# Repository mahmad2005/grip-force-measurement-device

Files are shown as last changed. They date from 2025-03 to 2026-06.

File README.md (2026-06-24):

# Hand Grip Force and Trajectory Measurement System

## Overview

This project focuses on the development of a portable, intelligent device designed to measure **hand grip force** and **object trajectory** for neurological assessment, particularly in patients with **stroke** or **Multiple Sclerosis (MS)**.

## Key Features

- 🧠 **Neurological Focus**  
  Designed to evaluate motor function, coordination, and rehabilitation progress in stroke and MS patients.

- 🔧 **Core Technologies**
  - **STM32 Microcontrollers** – Real-time data acquisition and processing
  - **Pressure Sensors** – High-resolution spatial grip force measurement
  - **Gyroscope & IMU Sensors** – Motion and orientation tracking of held objects
  - **Bluetooth** – Wireless data transmission to PC/mobile apps
  - **RTOS** – Deterministic multitasking on embedded systems
  - **Embedded Linux** – Advanced data handling and UI support

## System Architecture

[ Pressure Sensor ] [ Gyroscope / IMU ]
| |
[ Analog Front End ] |
| |
[ STM32 MCU ] <--> [ Bluetooth Module ]
|
[ Data Logger / Wi-Fi ]
|
[ Embedded Linux Platform ]

## Use Case

The system enables clinicians and researchers to:
- Quantitatively assess hand grip strength and control
- Track and visualize object movement during gripping tasks
- Analyze neuromuscular impairments and rehabilitation outcomes

## Future Work

- 🔬 Integration with AI models for predictive analysis  
- 📱 Mobile app for real-time data visualization  
- 🌐 Cloud-based data synchronization and reporting

---

**Developed using:**  
`C/C++ (STM32 HAL)`, `FreeRTOS`, `Python`, `Embedded Linux`, `Bluetooth Low Energy (BLE)`

---

> 📍 *This project is part of ongoing research in neuromuscular assessment and assistive rehabilitation technology.*

## � Developer Docs and Quick Start

- Protocol and wiring details (pins, SPI/UDP framing): `docs/System_Protocol_and_Wiring.md`
- Hardware overview and BOM highlights: `hardware/README.md`

Visualizer quick start (Windows cmd):

1) Install Python packages
  - Open a terminal and run:
    - `python -m pip install -r software\requirements.txt`
2) Set your listen IP/port in `software\viz_config.json` if needed (defaults to 0.0.0.0:12345)
3) Run the visualizer
  - `python software\run_visualizer.py`

Make sure the ESP32 sketch `firmware/esp32/ESP32_C3_Zero_SPI_2048_UDP.ino` has `udpAddress` set to your PC’s IP.

## �🔧 New Design

This section features the redesigned pressure sensor and control PCB with updated layout and schematic.

| Front View | Back View |
|---|---|
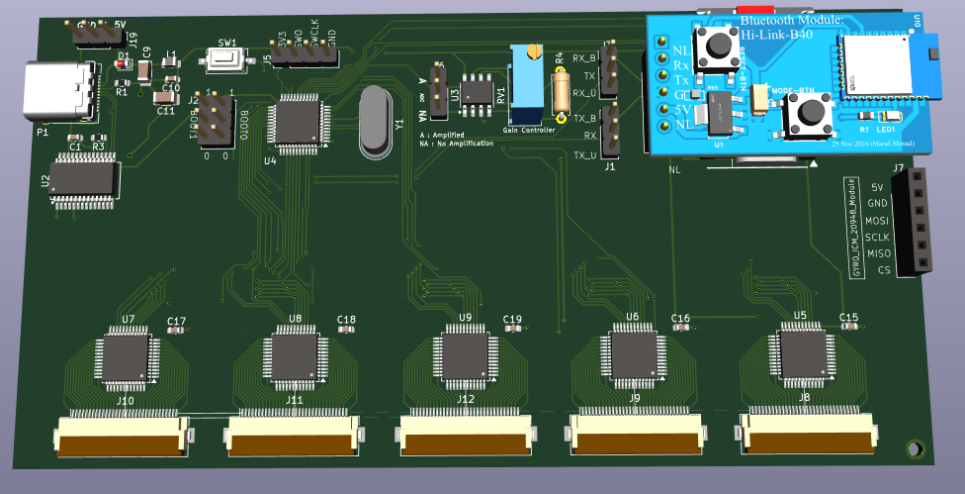
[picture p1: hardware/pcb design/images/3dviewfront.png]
3D View Front
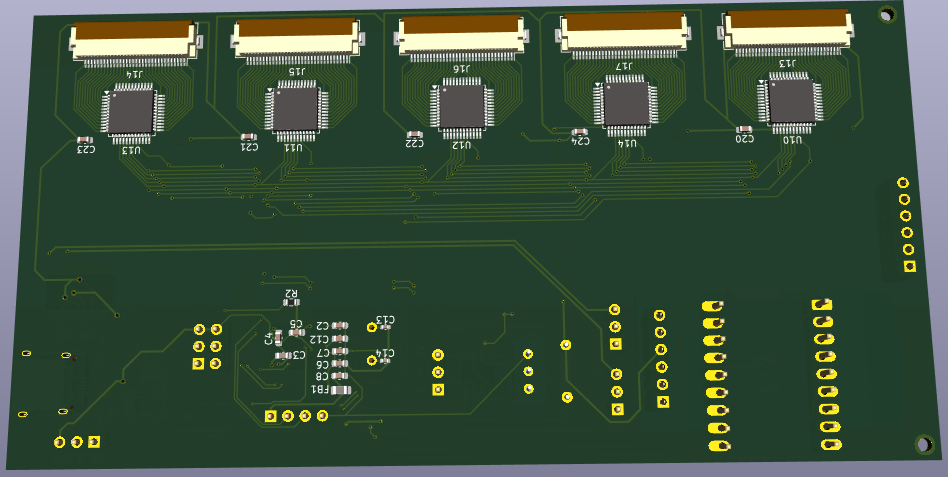
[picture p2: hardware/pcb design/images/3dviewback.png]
3D View Back
|  |  |
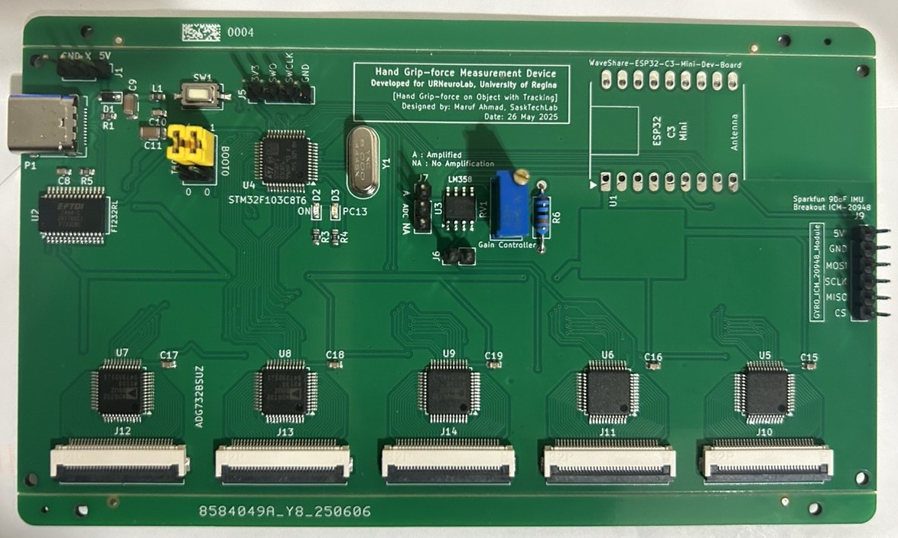
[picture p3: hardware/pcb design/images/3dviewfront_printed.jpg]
3D View Front
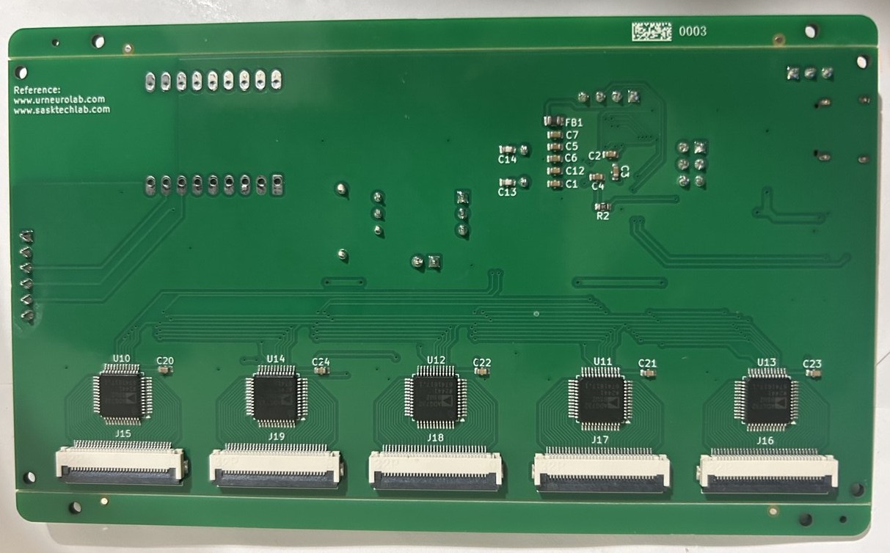
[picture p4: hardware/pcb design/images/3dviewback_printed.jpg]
3D View Back
|  |  |

### 🧩 Schematic

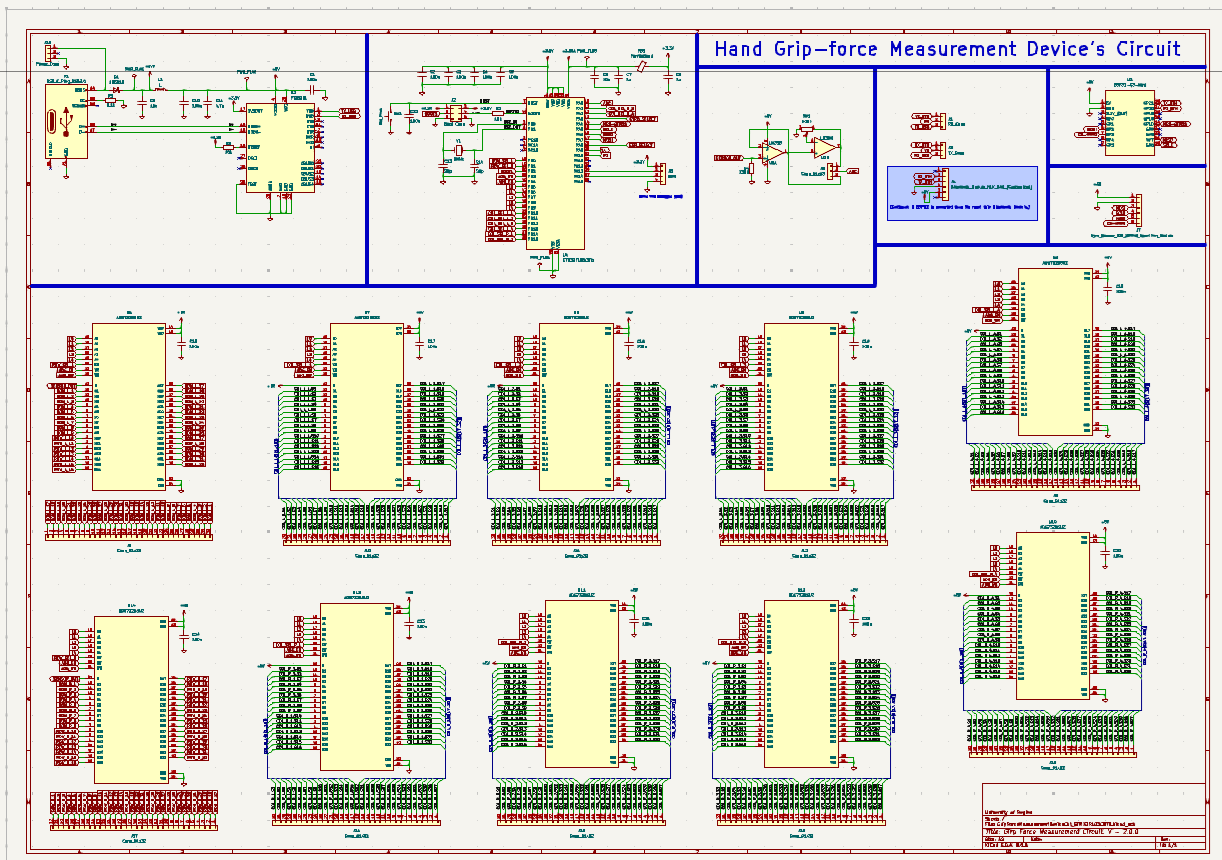
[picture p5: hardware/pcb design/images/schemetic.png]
Schematic


### 3D View of the Pressure Sensor Pad
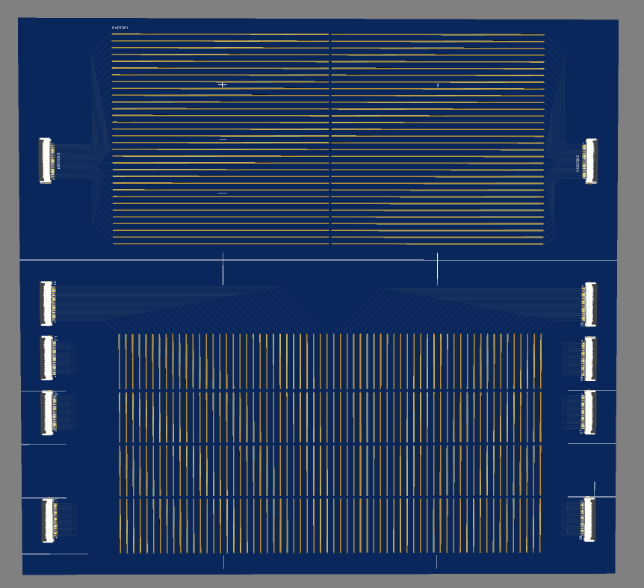
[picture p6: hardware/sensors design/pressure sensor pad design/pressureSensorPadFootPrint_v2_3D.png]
Pressure Sensor Pad 3D


## 📂 Previous Design

This section showcases the earlier versions of the PCB and sensor module designs for the Hand Grip Force Measurement Device.

| 3D View | 3D View (with Bluetooth Module) |
|---|---|
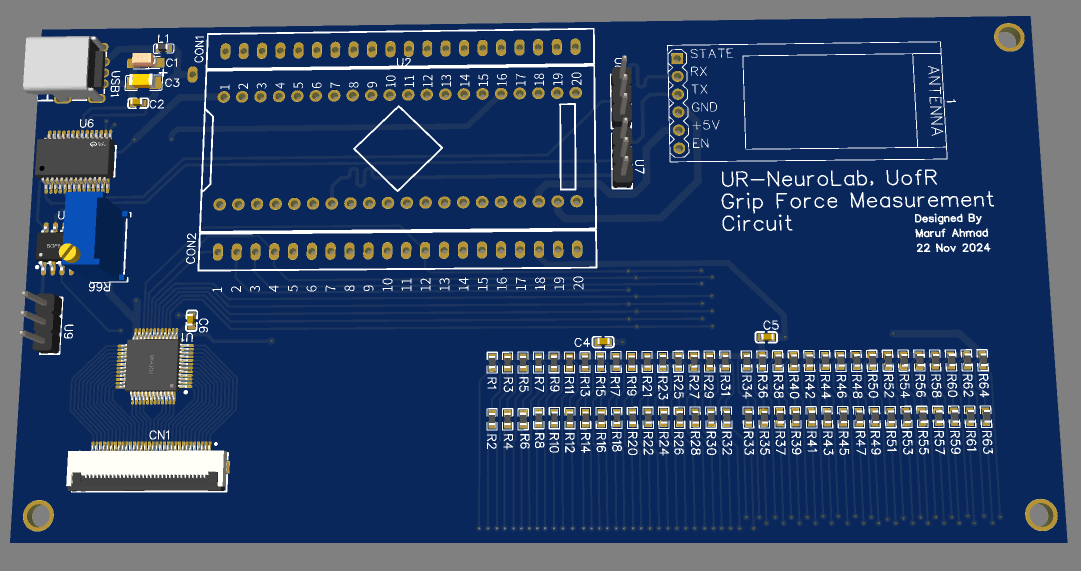
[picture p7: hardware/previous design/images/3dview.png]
3D View
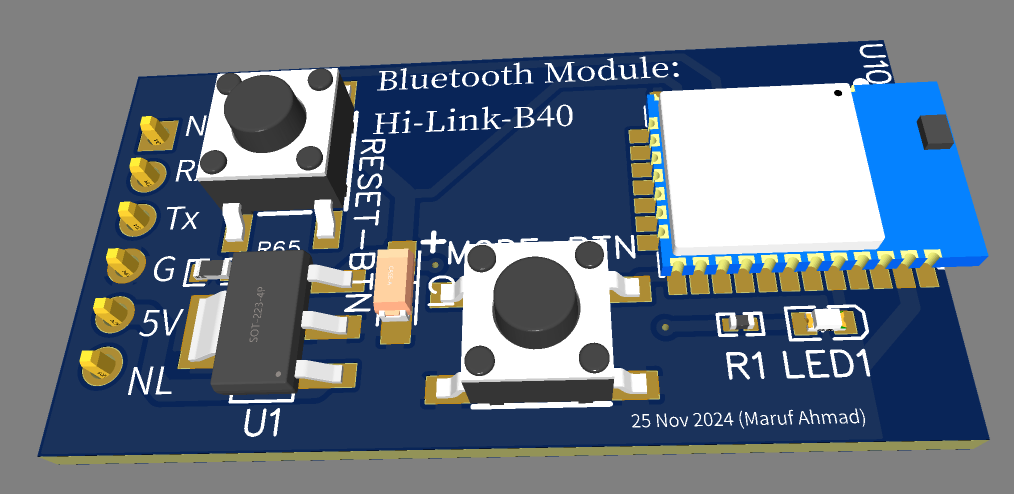
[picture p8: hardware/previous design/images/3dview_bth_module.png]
3D View BTH Module
|  |  |

| PCB Layout | PCB Layout (with Bluetooth Module) |
|---|---|
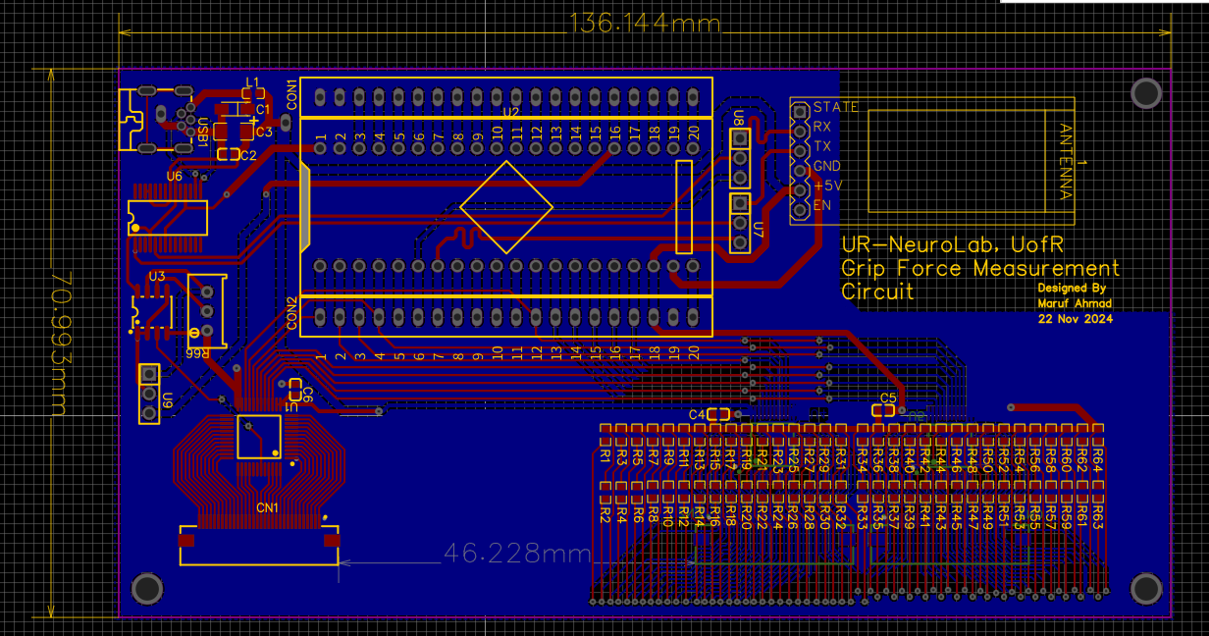
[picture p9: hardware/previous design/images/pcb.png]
PCB
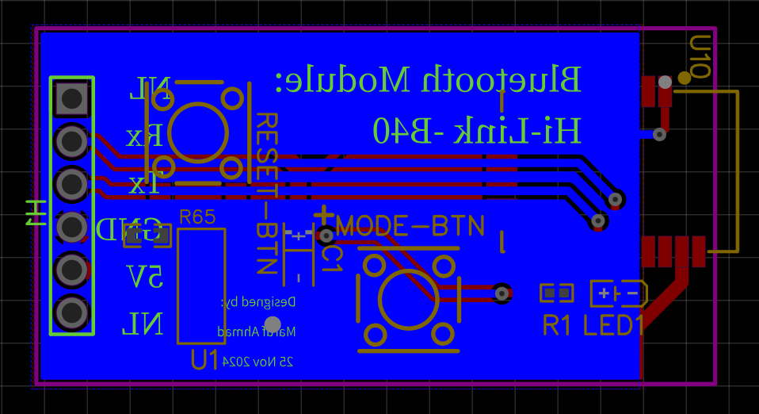
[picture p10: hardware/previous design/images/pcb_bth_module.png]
PCB BTH Module
|  |  |

### 🧪 Assembly and Testing Photos

These images capture key stages of the prototype development, including hardware assembly, sensor components, and testing setup.

| Internal Circuit | Grip Force Testing | PCB in Action |
|---|---|---|
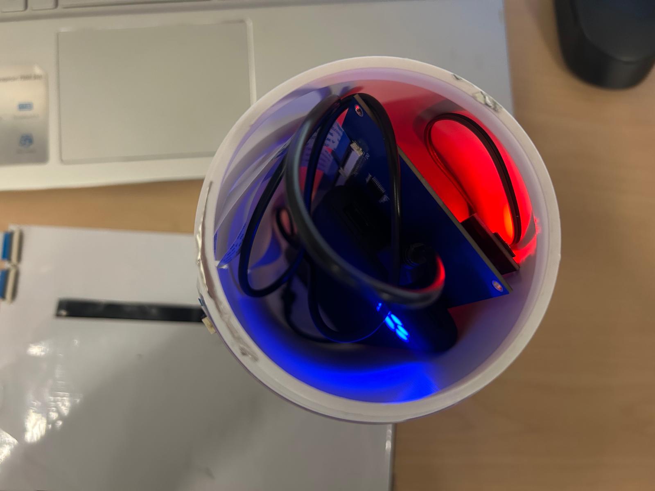
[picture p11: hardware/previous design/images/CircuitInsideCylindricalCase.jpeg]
Circuit Inside
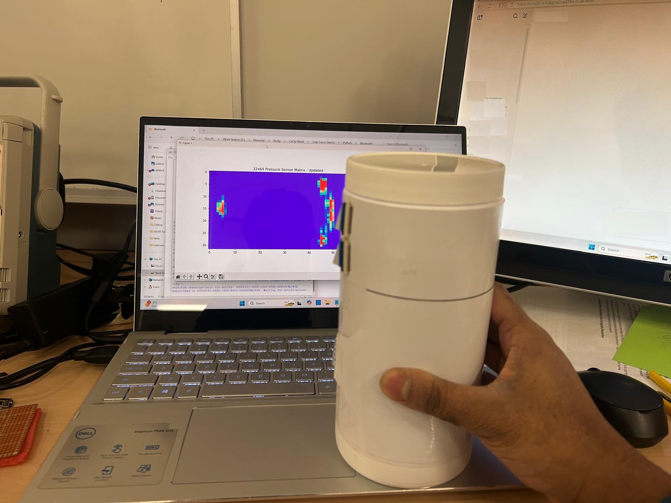
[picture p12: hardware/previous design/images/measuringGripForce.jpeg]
Grip Force Test
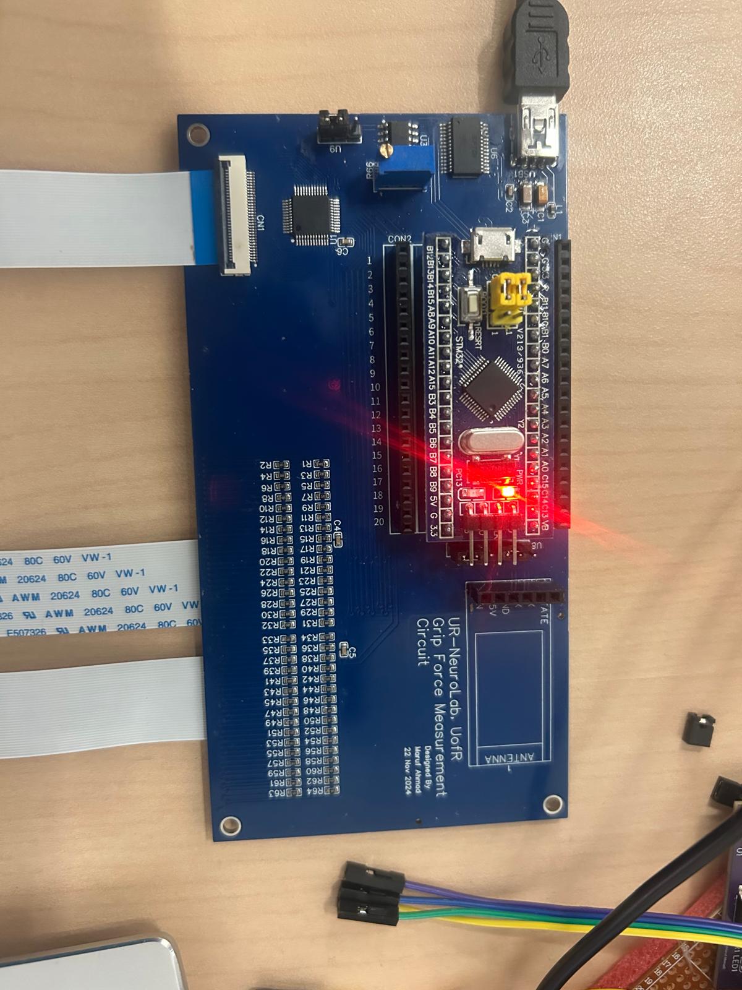
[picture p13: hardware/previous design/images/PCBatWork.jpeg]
PCB at Work
|  |  |  |

These photos show physical testing and assembly steps:
- Internal circuit mounted inside a cylindrical 3D-printed case.
- Testing hand grip force with the pressure sensor system connected to a display.
- Powered PCB with Bluetooth module running in real hardware.

| Pressure Sensor Pad | Pressure Sensing Demo |
|---|---|
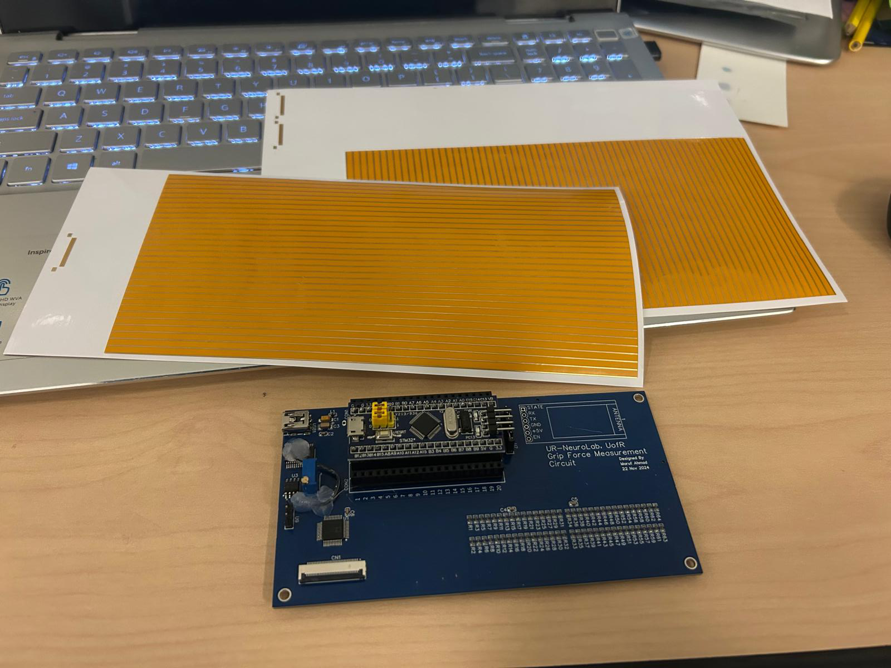
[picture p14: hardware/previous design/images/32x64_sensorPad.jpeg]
Sensor Pad
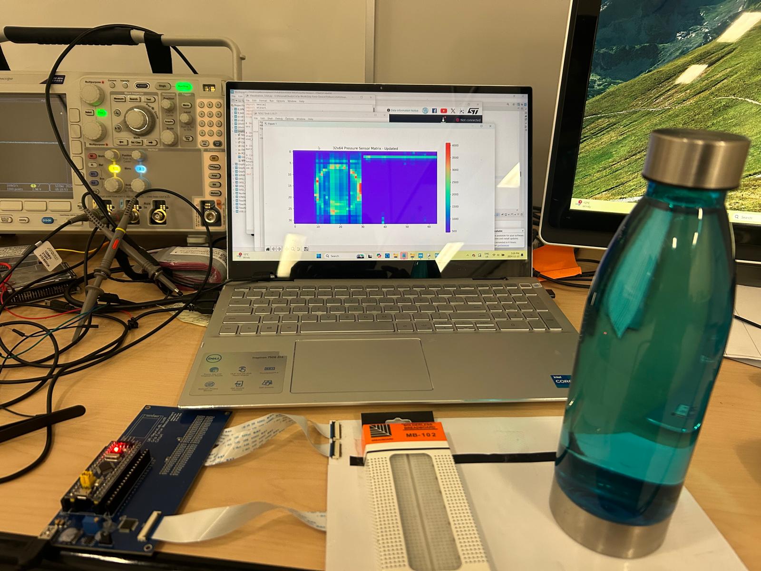
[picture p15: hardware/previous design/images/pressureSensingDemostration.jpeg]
Demo Setup
|  |  |

## Application View

Below is a sample visualization of the grip force device showing the **32×64 pressure map** along with gyroscope, accelerometer, and magnetometer data:

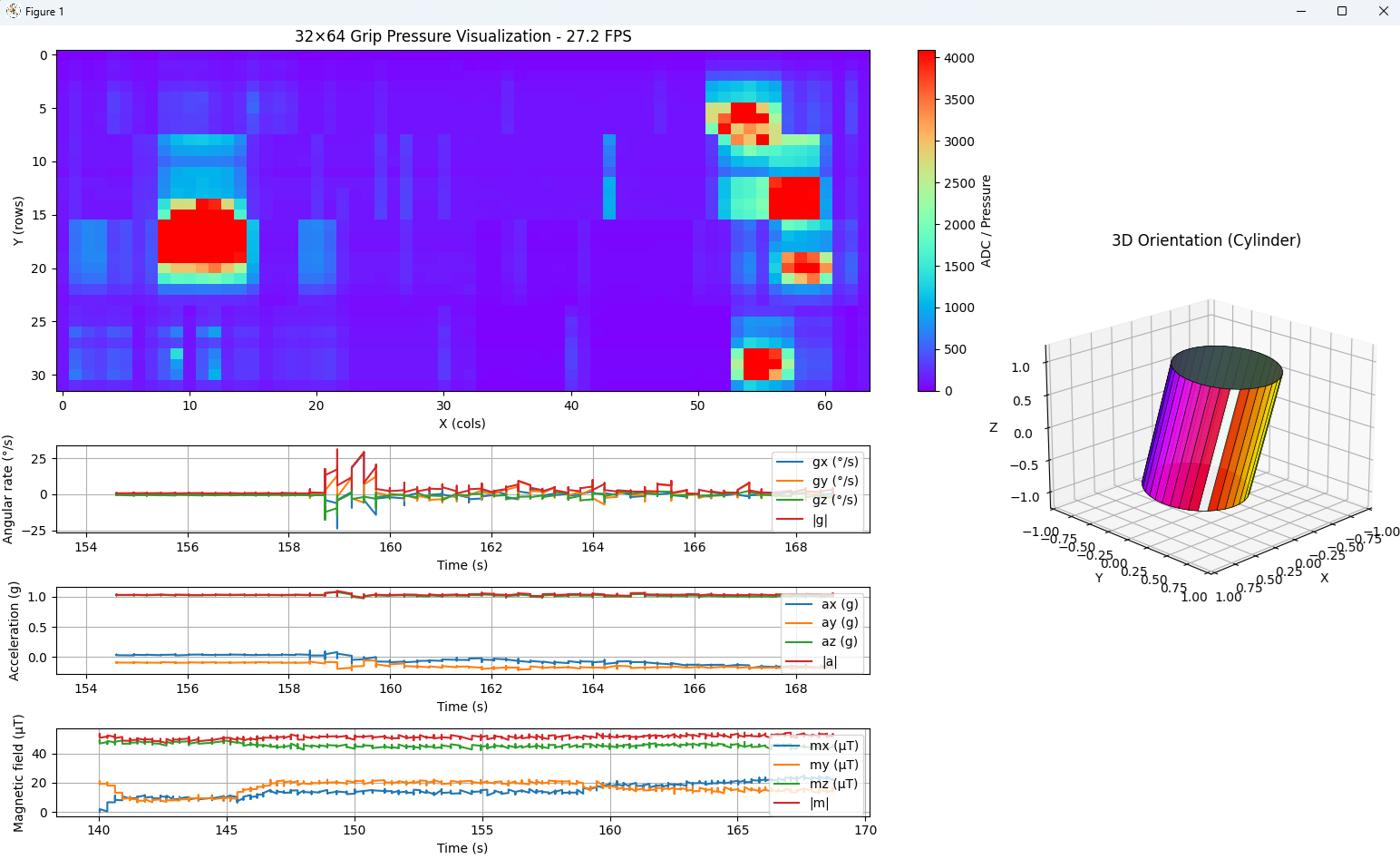
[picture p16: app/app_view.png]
Application View


## 🎥 Demonstration Video

Real-Time AprilTag Cylinder Tracking (https://www.youtube.com/watch?v=EXzzfofSnuo)

**Real-Time AprilTag Cylinder Tracking with 2D/3D Overlap Visualization**

Click the image above to watch the demonstration video on YouTube.

## 📄 Video Description

This video demonstrates a **real-time vision-based tracking system** using **AprilTags** to estimate and visualize the position of a cylindrical object.  
The system overlays **2D and 3D representations** to show precise alignment and movement tracking, supporting validation of object trajectory and spatial accuracy for experimental and rehabilitation-focused applications.

---

## 🎬 Recent Updates & New Demonstration

### New GripForce 3D Viewer Demo

GripForce 3D Viewer Software Outlook (https://www.youtube.com/watch?v=9zOydEpcdT4)

**Watch the new 3D Viewer software demonstration:**  
[GripForce 3D Viewer Software Outlook – YouTube](https://www.youtube.com/watch?v=9zOydEpcdT4)

This video showcases the updated **3D visualization interface** with improved **pressure heatmap display**, **real-time IMU data plots**, and **orientation cylinder rendering**.

### Updated 3D Simulator Visual

A new high-resolution screenshot showing the **GripForce 3D Simulator interface** is now available:

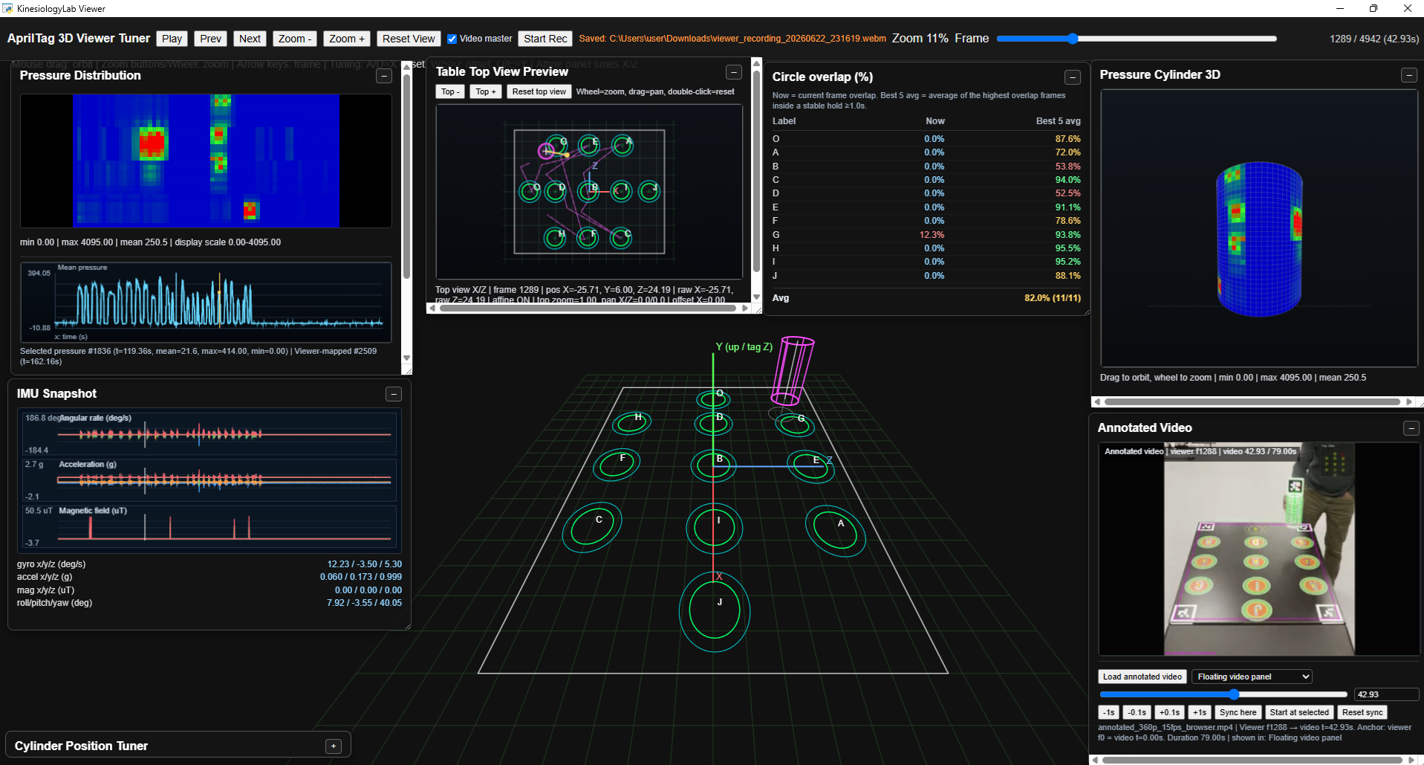
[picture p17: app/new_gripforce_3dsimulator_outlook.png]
GripForce 3D Simulator Outlook


**Recent updates:** Improve viewer sync, graph zoom, and persistent panel layout

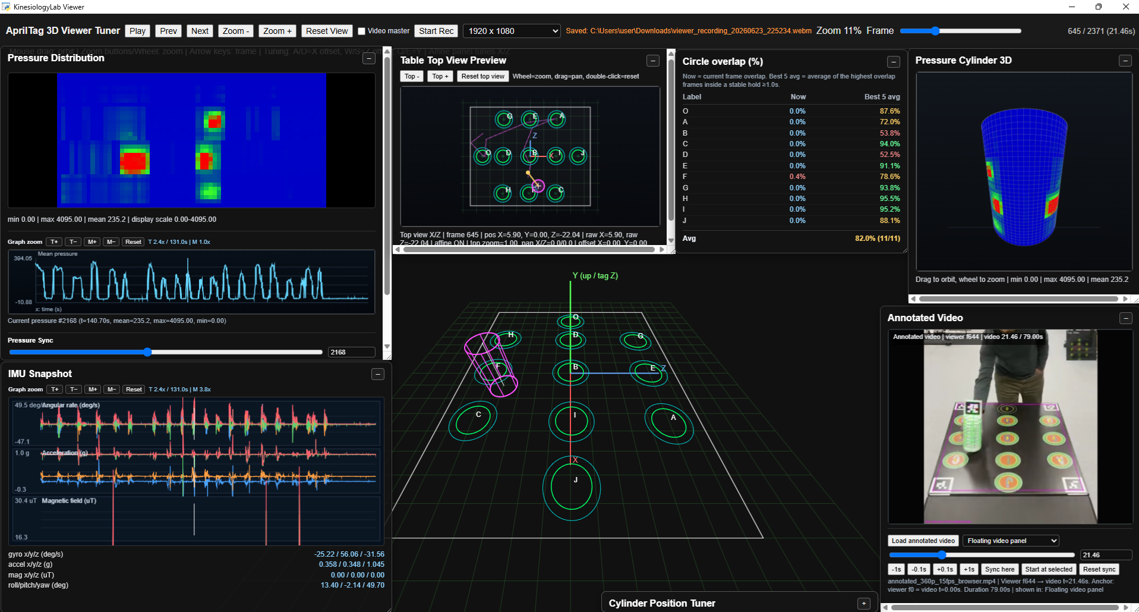
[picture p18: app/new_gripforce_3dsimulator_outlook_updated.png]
GripForce 3D Simulator Outlook


This demonstrates the enhanced UI with:
- Realistic 3D pressure blob movement
- Real-time gyroscope, accelerometer, and magnetometer traces
- 3D orientation object (cylinder) rendering
- Adjustable FPS and parameter controls

---

## 🖥️ Application Components

### Pressure Distribution Visualization

- **32×64 heatmap** showing live grip force across the entire sensor pad
- **Adaptive color scaling** with configurable min/max pressure (default: 0–4095)
- **Transformation options**: flip, rotate, or half-mirror for sensor orientation
- **Real-time animation** at ~60 fps (configurable)
- **Non-stretching display**: maintains aspect ratio during window resize

### IMU Data Visualization

- **3 simultaneous data streams**:
  - **Gyroscope**: angular velocity (°/s) at ±250 dps
  - **Accelerometer**: linear acceleration (g) at ±2 g
  - **Magnetometer**: magnetic field (µT)
- **Dual plot modes**:
  - **Per-component**: separate traces for X, Y, Z channels
  - **Magnitude-only**: single trace per sensor type
- **Sliding window buffer**: default 800 samples, configurable
- **Real-time animated plots** with live data injection

### 3D Object Orientation

- **Interactive 3D cylinder** representing held object
- **Quaternion-to-rotation-matrix** conversion from IMU orientation
- **Real-time 3D rendering** alongside 2D plots
- **Optional mode**: can be toggled on/off in visualizer

### Simulator (No Hardware Needed)

- **Realistic pressure patterns**: moving circular blobs with velocity
- **Simulated IMU oscillations**: smooth gyro, accel, mag data
- **UDP broadcast**: sends packets identical to real hardware
- **Interactive mode**: optional GUI for parameter control (`simulator_gui.py`)
- **Perfect for testing** without connected hardware

---

## 🌐 Web Viewer & Pose Acquisition

### Standalone Desktop Viewer

A **pywebview-based desktop application** for viewing 4K video annotated with AprilTag pose data:

```bash
# Launch from command line:
python run_viewer_standalone.bat

# Or manually:
python app/device_pose_acquisition/auto_target_detections/viewer_7371/standalone_viewer.py
```

**Features**:
- Frame-by-frame playback of annotated video
- Overlay circles and pose estimation data
- Synchronized pressure and IMU timeline (if available)
- Portable: single HTML file with embedded data

### AprilTag Pose Detection & Video Annotation

Process 4K video to detect **cylinder position and orientation** using AprilTags:

```bash
python app/device_pose_acquisition/auto_target_detections/detect_apriltag_pose_fixed11_4k.py \
  --video input.mp4 \
  --annotated-out output.mp4 \
  --export-viewer-data viewer_folder \
  --process-fps 15
```

**Output**:
- **Annotated MP4**: overlays detected circles and pose estimates
- **Viewer Data JSON**: frame-by-frame detection results
- **Viewer HTML**: self-contained, portable viewer with embedded data

**Optional Processing**:
- `--start-frame N, --end-frame N`: process specific frame range
- `--undistort`: apply camera calibration correction
- `--max-frames 0`: process all frames (default)

### Video Resizing for Web Playback

Optimize annotated videos for browser streaming:

```bash
# 720p
ffmpeg -vf "scale=1280:-2" -c:v libx264 -crf 23 input.mp4 output_720p.mp4

# 360p, 15 fps
ffmpeg -vf "fps=15,scale=-2:360" -c:v libx264 -crf 27 input.mp4 output_360p_15fps.mp4

# 240p, 15 fps
ffmpeg -vf "fps=15,scale=-2:240" -c:v libx264 -crf 28 input.mp4 output_240p_15fps.mp4
```

---

## 📁 App Folder Contents & File Guide

### `app/` Directory Structure

```
app/
├── app_view.png                           # Screenshot of pressure + IMU visualizer
├── new_gripforce_3dsimulator_outlook.png  # New 3D simulator interface screenshot
├── 3dsimulator_view.png                   # 3D simulator demo view
├── README.md                              # App-specific documentation
│
├── device_data_acquisitiom/               # Real-time data acquisition & visualization
│   ├── simulator.py                       # Simulates realistic pressure/IMU data (no hardware)
│   ├── simulator_gui.py                   # Interactive GUI for simulator
│   ├── viz_full_with_gyro_accel_mag.py    # Standard 2D visualizer
│   ├── viz_full_with_gyro_accel_mag_3Dobj.py  # 2D visualizer + 3D cylinder
│   ├── run_viz_app.bat                    # Launcher for standard visualizer
│   ├── run_viz_3D.bat                     # Launcher for 3D visualizer
│   └── README.txt                         # Device acquisition documentation
│
└── device_pose_acquisition/               # Video processing & web viewer
    ├── 4k_video_process/
    │   ├── extract_frames.py              # Extract frames from video
    │   ├── manual_reference_circle_alphabet_labeler_4k_best_images.py  # Reference marker UI
    │   ├── sessions/                      # NDJSON pressure/IMU replay data
    │   │   ├── session1.ndjson
    │   │   ├── session_2.ndjson
    │   │   └── ...
    │   └── accuracy_analyzer/
    │       ├── Note.txt                   # Command examples for video processing
    │       └── detect_apriltag_pose_*.py  # Various AprilTag detection scripts
    │
    └── auto_target_detections/
        ├── detect_apriltag_pose_fixed11_4k.py  # Main AprilTag detector (exports viewer data)
        ├── extract_frames.py              # Frame extraction utility
        └── viewer_7371/                   # Web viewer assets
            ├── viewer.html                # Portable viewer template
            ├── viewer_data.json           # Exported frame data
            ├── standalone_viewer.py       # Desktop launcher
            └── session.ndjson, session_2.ndjson  # Example session files
```

### How to Use Each File

| File | Usage |
|---|---|
| **simulator.py** | Start with `python simulator.py --ip 127.0.0.1 --port 12345 --fps 60` to test visualizer without hardware |
| **viz_full_with_gyro_accel_mag.py** | Main visualizer; shows pressure + IMU data |
| **viz_full_with_gyro_accel_mag_3Dobj.py** | Enhanced visualizer with 3D object rendering |
| **detect_apriltag_pose_fixed11_4k.py** | Process 4K video to export annotated frames and viewer data |
| **viewer.html** | Open in browser or desktop app to view posed video frames |
| **session*.ndjson** | Replay recorded pressure/IMU data; import into analysis tools |

---

## 📊 Data Formats

### Pressure Data

- **32 rows × 64 columns** (2048 total samples per frame)
- **UDP packets**: 10 packets per frame, 205 uint16 values per packet
- **Data type**: uint16, little-endian
- **Range**: 0–4095 (raw 12-bit ADC)
- **Default endpoint**: UDP `0.0.0.0:12345`
- See `docs/System_Protocol_and_Wiring.md` for detailed packet structure

### IMU Data

- **Gyroscope**: ±250 dps (131.0 LSB/deg/s)
- **Accelerometer**: ±2 g (16384.0 LSB/g)
- **Magnetometer**: ±120 µT (0.15 µT/LSB, AK09916 sensor)
- **Update rate**: ~60 fps (synchronized with pressure frames)
- **Format**: big-endian int16 values with header: `b'\xAA\x55IM'`

### Viewer Data (JSON Export)

- **Self-contained HTML** with embedded frame data
- **Per-frame annotations**: circle overlays, pose estimates, detection results
- **Portable format**: open in any browser or desktop viewer
- Generated by `detect_apriltag_pose_fixed11_4k.py --export-viewer-data <path>`

### Session Data (NDJSON)

- **Streaming-safe newline-delimited JSON**
- **One JSON object per line** (metadata + frames)
- **Contains**: frame_idx, timestamp, flattened pressure array, IMU components
- **Schema**: `kinesiology.pressure_imu.ndjson.v1`
- **Use case**: replay in web viewer, time-series analysis

---

## 🎯 Quick Start Guide

### 1. **Test Without Hardware** (Simulator)

```bash
# Terminal 1: Run simulator
cd app/device_data_acquisitiom
python simulator.py --ip 127.0.0.1 --port 12345 --fps 60

# Terminal 2: Run visualizer
python viz_full_with_gyro_accel_mag.py --ip 0.0.0.0 --port 12345 --show-magnitude
```

Or use batch files:
```bash
run_viz_app.bat      # Standard visualizer
run_viz_3D.bat       # 3D visualizer
```

### 2. **Process 4K Video & Export Viewer Data**

```bash
cd app/device_pose_acquisition/auto_target_detections
python detect_apriltag_pose_fixed11_4k.py \
  --video path/to/video.mp4 \
  --annotated-out output.mp4 \
  --export-viewer-data viewer_output
```

Then open `viewer_output/viewer.html` in a browser or desktop viewer.

### 3. **With Real Hardware**

1. Program **ESP32** with `firmware/esp32/ESP32_C3_Zero_SPI_2048_UDP.ino` (set your PC IP)
2. Program **STM32F103C8T6** with firmware in `firmware/stm32f103c8t6/`
3. Connect pressure sensor pad to multiplexer chain (see pinouts in `docs/System_Protocol_and_Wiring.md`)
4. Run visualizer:
   ```bash
   python viz_full_with_gyro_accel_mag.py --ip 0.0.0.0 --port 12345 --show-magnitude
   ```

---

## 📖 Full Project Documentation

For comprehensive technical details, see:

- **[INSTRUCTIONS.md](INSTRUCTIONS.md)** — Project rules, data formats, development guidelines
- **[docs/System_Protocol_and_Wiring.md](docs/System_Protocol_and_Wiring.md)** — Pinouts, SPI/UDP packet structure, timing specs
- **[hardware/README.md](hardware/README.md)** — KiCad project, BOM, component references
- **[app/README.md](app/README.md)** — Visualizer usage, simulator commands, viewer workflow

---

## ❓ Frequently Asked Questions

**Q: Can I use the system without hardware?**  
A: Yes! Run the simulator (`simulator.py`) to generate realistic pressure and IMU data.

**Q: What video formats are supported?**  
A: MP4, MOV, AVI (via OpenCV). 4K video (3840×2160) is recommended for AprilTag detection.

**Q: How do I export data for statistical analysis?**  
A: Use NDJSON session files (see Session Data format) or export viewer JSON. Both are Python/R compatible.

**Q: Can I visualize multiple sessions simultaneously?**  
A: Not in the current version. Planned for future releases.

**Q: Is there a mobile app?**  
A: Mobile support is planned for future versions. Currently PC-only (Windows/Linux/Mac).

---

## 📝 Notes from Previous Work

*Summarized from `app/device_pose_acquisition/4k_video_process/accuracy_analyzer/Note.txt`:*

### AprilTag Processing: Script Variants & Frame Range Control

The project includes **three AprilTag detection script variants**. Choose based on your needs:

#### Script Variants

| Script | Use Case | Key Features |
|---|---|---|
| **detect_apriltag_pose_fixed11_4k.py** | Main production script | Full video processing, camera matrix auto-scaling |
| **detect_apriltag_pose_fixed11_4k_option3_single_state.py** | Simplified variant | Fewer options, single tracking mode |
| **detect_apriltag_pose_fixed11_4k_option3_single_state_start_end_frame.py** | **Best for testing/partial processing** | Frame range control (`--start-frame`, `--end-frame`) |

#### Key Parameters Explained

- **`--start-frame N`** — Begin processing at frame N (1-based). Default: 1
- **`--end-frame N`** — Stop processing at frame N, inclusive. Default: 0 (process until video ends)
- **`--process-fps F`** — Limit processing to F fps (e.g., 15). Skips frames to reduce computation. Default: 0 (no limit)
- **`--max-frames N`** — Process only N frames starting from `--start-frame`. Default: 0 (no limit)
- **`--annotated-out FILE`** — Write video with overlays drawn (AprilTag pose, cylinder, axes)
- **`--export-viewer-data PATH`** — Generate interactive 3D viewer HTML + JSON data to PATH folder or .json file

#### Usage Examples

**Example 1: Quick test (first 150 frames, 5 fps)**
```powershell
python detect_apriltag_pose_fixed11_4k.py `
  --video input.mov `
  --annotated-out output.mp4 `
  --max-frames 150 `
  --process-fps 5
```

**Example 2: Full video with viewer export**
```powershell
python detect_apriltag_pose_fixed11_4k.py `
  --video input.mov `
  --annotated-out output.mp4 `
  --export-viewer-data ./viewer_output `
  --process-fps 15
```

**Example 3: Frame range (test specific section, e.g., 19 June capture)**
```powershell
python detect_apriltag_pose_fixed11_4k_option3_single_state_start_end_frame.py `
  --video IMG_006_19June.mov `
  --annotated-out annotated_IMG_006_19June.mp4 `
  --export-viewer-data ./viewer_006_19June `
  --process-fps 15 `
  --start-frame 300 `
  --end-frame 900
```

#### Output Files Created

Each command generates:

- **`annotated_*.mp4`** — Video file with AprilTag overlays (boxes, axes, cylinder object)
- **`viewer_output/`** (if using `--export-viewer-data`):
  - `viewer.html` — Self-contained interactive 3D viewer (open in browser)
  - `viewer_data.json` — Extracted frame data (frame index, detected tags, poses, circle overlaps)
  - Optional: `viewer_data_overlay.json`, pose history CSV

#### Processing Tips

- **For testing**: Use `--start-frame` and `--end-frame` to process only the section you care about
- **For speed**: Reduce `--process-fps` (e.g., 5 fps processes 5 frames per second of video)
- **For accuracy**: Keep `--process-fps` high (15+) or omit it for full precision
- **For web playback**: Use FFmpeg to resize annotated videos (see next section)

### Video Format Optimization

The Note.txt includes FFmpeg commands for resizing annotated videos for web playback (720p, 360p, 240p variants).

---

## ❓ Needs Confirmation

The following items need clarification or user confirmation:

1. **New Demonstration Video Purpose**
   - URL: `https://www.youtube.com/watch?v=0S4J9DHq-p0`
   - Context: Is this a 3D viewer demo, new features showcase, or user workflow guide?

2. **Web Viewer Path Consistency**
   - Previous docs reference `web_viz_app/` but current code uses `device_pose_acquisition/auto_target_detections/viewer_7371/`
   - Should legacy paths be updated or maintained for backward compatibility?

3. **Session Data Archiving**
   - How should users manage large NDJSON files (>1 GB)?
   - Is cloud storage integration planned?

4. **Pressure Calibration**
   - Are there reference calibration procedures or known sensor limitations?
   - Should calibration UI be prioritized for next release?

5. **Multi-platform Support**
   - Current `.bat` files are Windows-only. Are Linux/macOS batch files needed?
   - Should the project add `.sh` shell scripts?

---

## Contributing & Support

For bug reports, feature requests, or contributions, please refer to the **[INSTRUCTIONS.md](INSTRUCTIONS.md)** for project rules and development guidelines.

---

> **Last Updated**: June 22, 2026  
> **Maintained by**: KinesiologyLab Team  
> **License**: [Specify as needed]

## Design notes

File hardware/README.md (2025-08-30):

# Hardware overview

This folder contains the KiCad project, 3D models, and prior design assets for the Grip Force Measurement Device.

## KiCad project

Project: `pcb design/GripForceMeasurementDeviceCkt_STM32F103C8T6/`

Key files:
- `GripForceMeasurementDeviceCkt_STM32F103C8T6.kicad_sch` — schematic
- `GripForceMeasurementDeviceCkt_STM32F103C8T6.kicad_pcb` — board layout
- `GripForceMeasurementDeviceCkt_STM32F103C8T6.pdf` — exported drawing/PDF (present)
- `gerberAll/` — manufacturing outputs

3D models and references: see `pcb design/3D-Models-Step-files/`

## BOM highlights (from IPC-2581 XML)

- MCU: STM32F103C8Tx (LQFP‑48)
- Multiplexers: ADG732BSUZ (16‑to‑1 analog switch, multiple devices used to reach 32×64)
- Wireless module: ESP32‑C3‑Mini (through‑hole variant footprint)
- IMU header: SparkFun ICM‑20948 module (6‑pin socket)

For a full BOM, open the KiCad project or review the IPC‑2581 XML at:
`pcb design/GripForceMeasurementDeviceCkt_STM32F103C8T6/GripForceMeasurementDeviceCkt_STM32F103C8T6.xml`

## Notes

- Signal levels are 3V3.
- SPI runs between ESP32‑C3 (master) and STM32F103 (slave). Ensure a clean ground reference and short interconnects.
- The sensor matrix connects to the ADG732 network; ADC measures on PA0.

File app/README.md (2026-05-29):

# KinesiologyLab Grip Pressure + IMU Visualization System

## Project Description

This project provides a real-time visualization system for a 32×64 grip pressure sensor array combined with IMU (gyroscope, accelerometer, magnetometer) data. It is designed for research or clinical applications in kinesiology, biomechanics, or hand function studies. The system can visualize live data from real hardware or from a built-in simulator that generates realistic sensor data.

### Features
- Real-time heatmap visualization of grip pressure (32×64 grid)
- Real-time plots of gyroscope, accelerometer, and magnetometer data
- 3D orientation visualization (with the 3D visualizer)
- Optional CSV logging
- Simulator for development/testing without hardware

### Screenshots

3D simulator view:

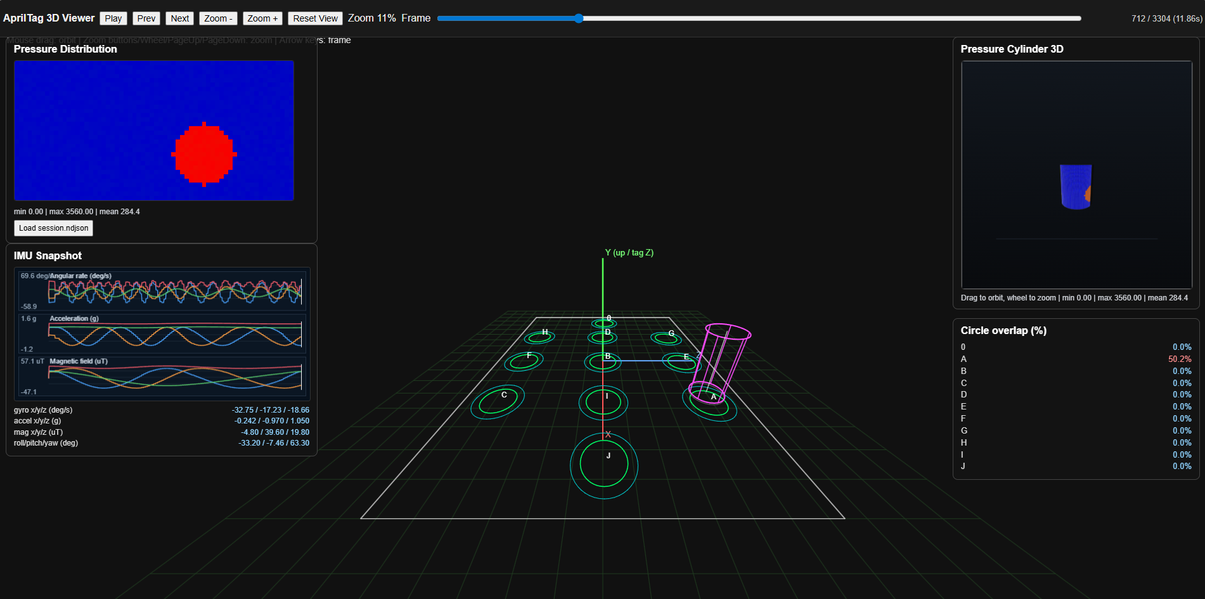
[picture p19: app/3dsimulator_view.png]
3D simulator view


App view:

App view

---

## How to Use

### 1. Run the Simulator (No Hardware Needed)
Open a terminal in the `app` folder and run:

```
python simulator.py --ip 127.0.0.1 --port 12345 --fps 60
```
- `--ip` and `--port` must match the visualizer settings (default is 127.0.0.1:12345)
- `--fps` sets the update rate (frames per second)

### 2. Run the Visualization Software
Open a second terminal in the same folder. You can use either the batch files or run the Python scripts directly.

#### Standard Visualizer
```
python viz_full_with_gyro_accel_mag.py --ip 0.0.0.0 --port 12345 --show-magnitude
```
Or simply double-click/run:
```
run_viz_app.bat
```

#### 3D Visualizer
```
python viz_full_with_gyro_accel_mag_3Dobj.py --ip 0.0.0.0 --port 12345 --show-magnitude --show-3d
```
Or simply double-click/run:
```
run_viz_3D.bat
```

### 3. See Live Simulated Data
The visualizer will display animated, realistic grip and IMU data as if real hardware is connected.

### 4. Run the Web Viewer as a Standalone Desktop App
You can open `web_viz_app/viewer_7371/viewer.html` in its own desktop window (no browser tab):

```
run_viewer_standalone.bat
```

Or run directly:

```
python web_viz_app/viewer_7371/standalone_viewer.py
```

If needed, install the dependency once:

```
python -m pip install pywebview
```

### 5. AprilTag Export Viewer Workflow (Updated)
`web_viz_app/detect_apriltag_pose_fixed11_4k.py` supports exporting viewer artifacts with:

```
python web_viz_app/detect_apriltag_pose_fixed11_4k.py --export-viewer-data web_viz_app/viewer_7371
```

Export behavior:
- Writes `viewer_data.json` (sanitized numeric export data)
- Writes `viewer.html` (portable viewer with embedded data)
- Reuses the maintained viewer template from `web_viz_app/viewer_7371/viewer.html` (fallback: `viewer2.html`) and injects fresh exported data into it

Why `viewer.html` is still written:
- Keeps a single self-contained artifact that can be opened directly (including standalone desktop mode)
- Preserves compatibility with existing workflows while still reusing the shared template code

Note:
- The current exporter intentionally updates both files for portability and backward compatibility.

---

## GUI Simulator (Recommended)

`simulator_gui.py` is a full professional virtual hardware testing tool with a dark-themed control panel.

```
python simulator_gui.py --ip 127.0.0.1 --port 12345
```

Or start streaming automatically on launch:
```
python simulator_gui.py --ip 127.0.0.1 --port 12345 --auto-start
```

### GUI Features
- Live sliders for gx/gy/gz, ax/ay/az, mx/my/mz, pressure position/radius/strength, FPS
- AUTO / MANUAL toggle buttons for IMU and pressure
- Reset IMU button
- Start/Pause streaming button
- Live pressure map preview
- IMU readings display and actual FPS counter
- **Motion Presets**: Gripping, Rolling, Shaking, Twisting, Static Hold, Random Motion
- **Record** simulated sessions to CSV
- **Replay** recorded sessions
- Dark theme

---

## Keyboard-Only Simulator (Legacy)

```
python simulator.py --ip 127.0.0.1 --port 12345 --fps 60 --manual-imu --manual-pressure
```

---

## Example Commands (Quick Reference)

```
# Start GUI simulator (recommended)
python simulator_gui.py --ip 127.0.0.1 --port 12345 --auto-start

# Start keyboard simulator (legacy)
python simulator.py --ip 127.0.0.1 --port 12345 --fps 60

# Start standard visualizer
python viz_full_with_gyro_accel_mag.py --ip 0.0.0.0 --port 12345 --show-magnitude

# Start 3D visualizer
python viz_full_with_gyro_accel_mag_3Dobj.py --ip 0.0.0.0 --port 12345 --show-magnitude --show-3d
```

---

## Notes
- The simulator is a drop-in replacement for the real hardware device.
- You can adjust the simulator's FPS or add keyboard/mouse control for more interactive testing.
- Make sure Python and required packages (numpy, matplotlib) are installed.
- The visualizer and simulator must use the same IP and port.

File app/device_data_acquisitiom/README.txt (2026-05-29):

# KinesiologyLab Grip Pressure + IMU Visualization System

## Project Description

This project provides a real-time visualization system for a 32×64 grip pressure sensor array combined with IMU (gyroscope, accelerometer, magnetometer) data. It is designed for research or clinical applications in kinesiology, biomechanics, or hand function studies. The system can visualize live data from real hardware or from a built-in simulator that generates realistic sensor data.

### Features
- Real-time heatmap visualization of grip pressure (32×64 grid)
- Real-time plots of gyroscope, accelerometer, and magnetometer data
- 3D orientation visualization (with the 3D visualizer)
- Optional CSV logging
- Simulator for development/testing without hardware

---

## How to Use

### 1. Run the Simulator (No Hardware Needed)
Open a terminal in the `app` folder and run:

```
python simulator.py --ip 127.0.0.1 --port 12345 --fps 60
```
- `--ip` and `--port` must match the visualizer settings (default is 127.0.0.1:12345)
- `--fps` sets the update rate (frames per second)

### 2. Run the Visualization Software
Open a second terminal in the same folder. You can use either the batch files or run the Python scripts directly.

#### Standard Visualizer
```
python viz_full_with_gyro_accel_mag.py --ip 0.0.0.0 --port 12345 --show-magnitude
```
Or simply double-click/run:
```
run_viz_app.bat
```

#### 3D Visualizer
```
python viz_full_with_gyro_accel_mag_3Dobj.py --ip 0.0.0.0 --port 12345 --show-magnitude --show-3d
```
Or simply double-click/run:
```
run_viz_3D.bat
```

### 3. See Live Simulated Data
The visualizer will display animated, realistic grip and IMU data as if real hardware is connected.

### 4. Run the Web Viewer as a Standalone Desktop App
You can open `web_viz_app/viewer_7371/viewer.html` in its own desktop window (no browser tab):

```
run_viewer_standalone.bat
```

Or run directly:

```
python web_viz_app/viewer_7371/standalone_viewer.py
```

If needed, install the dependency once:

```
python -m pip install pywebview
```

### 5. AprilTag Export Viewer Workflow (Updated)
`web_viz_app/detect_apriltag_pose_fixed11_4k.py` supports exporting viewer artifacts with:

```
python web_viz_app/detect_apriltag_pose_fixed11_4k.py --export-viewer-data web_viz_app/viewer_7371
```

Export behavior:
- Writes `viewer_data.json` (sanitized numeric export data)
- Writes `viewer.html` (portable viewer with embedded data)
- Reuses the maintained viewer template from `web_viz_app/viewer_7371/viewer.html` (fallback: `viewer2.html`) and injects fresh exported data into it

Why `viewer.html` is still written:
- Keeps a single self-contained artifact that can be opened directly (including standalone desktop mode)
- Preserves compatibility with existing workflows while still reusing the shared template code

Note:
- The current exporter intentionally updates both files for portability and backward compatibility.

---

## Example Commands (Quick Reference)

```
# Start simulator
python simulator.py --ip 127.0.0.1 --port 12345 --fps 60

# Start standard visualizer
python viz_full_with_gyro_accel_mag.py --ip 0.0.0.0 --port 12345 --show-magnitude

# Start 3D visualizer
python viz_full_with_gyro_accel_mag_3Dobj.py --ip 0.0.0.0 --port 12345 --show-magnitude --show-3d
```

---

#Simmulator with GUI
python simulator_gui.py --ip 127.0.0.1 --port 12345 --auto-start 

#Viz with Gui
python viz_full_with_gyro_accel_mag_3Dobj.py --ip 0.0.0.0 --port 12345 --show-magnitude --show-3d

#Viz with Record
python viz_full_with_gyro_accel_mag_3Dobj.py --ip 0.0.0.0 --port 12345 --show-magnitude --show-3d --save-session-json web_viz_app/viewer_7371/session.ndjson

## Notes
- The simulator is a drop-in replacement for the real hardware device.
- You can adjust the simulator's FPS or add keyboard/mouse control for more interactive testing.
- Make sure Python and required packages (numpy, matplotlib) are installed.
- The visualizer and simulator must use the same IP and port.

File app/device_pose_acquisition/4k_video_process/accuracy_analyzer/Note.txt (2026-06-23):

python .\google_11.py --video ..\IMG_0005.MOV --annotated-out annotated_IMG_0005_5.mp4 --max-frames 150 --process-fps 5 --undistort 

python .\detect_apriltag_pose_fixed11_4k.py --video ..\IMG_0005.MOV --annotated-out annotated_IMG_0005_6.mp4 --max-frames 150 --process-fps 5 --undistort

detect_apriltag_pose_fixed11_4k_fixed_intrinsics.py

python .\detect_apriltag_pose_fixed11_4k_fixed_intrinsics.py --video ..\IMG_0005.MOV --annotated-out annotated_IMG_0005_6.mp4 --max-frames 150 --process-fps 5 --undistort

python .\detect_apriltag_pose_fixed11_4k_fixed_intrinsics.py --video ..\IMG_0005.MOV --annotated-out annotated_IMG_0005_8.mp4 --max-frames 0 --process-fps 15 --undistort --export-viewer-data .\viewer_0005

#To Process the 4K Video
python .\detect_apriltag_pose_fixed11_4k_option3_single_state.py --video ..\IMG_0006.mov --annotated-out annotated_IMG_0006_3.mp4 --export-viewer-data .\viewer_0006_3 --process-fps 15 --max-frames 0

#To Run the Viewr_xxxx.html
python -m http.server 8000 

#To Process the 4K Video. new 19 June
python .\detect_apriltag_pose_fixed11_4k_option3_single_state_start_end_frame.py --video ..\IMG_006_19June.mov --annotated-out annotated_IMG_006_19June.mp4 --export-viewer-data .\viewer_006_19June --process-fps 15 --start-frame 300 --end-frame 900

Annotated Video Resizer: 

#full
ffmpeg -y -i annotated_IMG_006_19June_p2.mp4 -c:v libx264 -pix_fmt yuv420p -preset veryfast -crf 23 -movflags +faststart -an annotated_IMG_006_19June_p2_browser.mp4

#720p
ffmpeg -y -i annotated_IMG_006_19June_p2.mp4 -vf "scale=1280:-2" -c:v libx264 -pix_fmt yuv420p -preset veryfast -crf 24 -movflags +faststart -an annotated_720p_browser.mp4

#360p
ffmpeg -y -i annotated_IMG_006_19June_p2.mp4 -vf "scale=-2:360" -c:v libx264 -pix_fmt yuv420p -preset veryfast -crf 27 -movflags +faststart -an annotated_360p_browser.mp4

#360 reduced fps
ffmpeg -y -i annotated_IMG_006_19June_p2.mp4 -vf "fps=15,scale=-2:360" -c:v libx264 -pix_fmt yuv420p -preset veryfast -crf 28 -movflags +faststart -an annotated_360p_15fps_browser.mp4

#240p
ffmpeg -y -i annotated_IMG_006_19June_p2.mp4 -vf "fps=15,scale=-2:240" -c:v libx264 -pix_fmt yuv420p -preset veryfast -crf 28 -movflags +faststart -an annotated_240p_15fps_browser.mp4

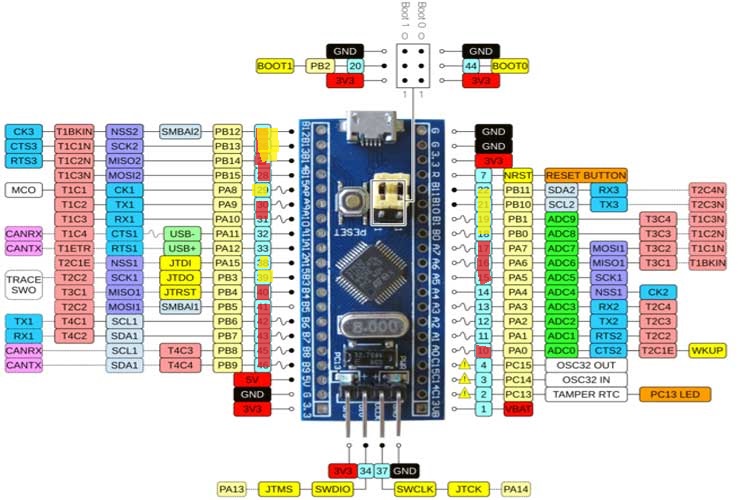
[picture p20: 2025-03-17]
components/stm32F103pinout/bluepill_pinout.jpg

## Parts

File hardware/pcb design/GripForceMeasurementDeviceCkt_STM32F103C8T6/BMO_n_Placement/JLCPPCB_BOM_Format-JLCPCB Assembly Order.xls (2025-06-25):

JLCPCB BOM Tool - BOM Matching
BOM name：JLCPPCB_BOM_Format-JLCPCB Assembly Order.xlsx |  |  | Download Time：2025-05-30 06:53:48 |  |  |  | * Our matching results are updated in real-time, but stock and prices may change. If it's been over 24 hours, please re-match before placing your order.
PCB Assembled Qty：5 |  |  | Est. Total Price：359.5268
Your BOM |  |  |  |  | Matched Parts |  |  |  |  |  |  | Order Information
Top Designator | Bottom Designator | Comment | Footprint | JLCPCB Part # | Matches | Part # | Manufacturer | Footprint | Description | Category | Warning | JLCPCB Part # | Product link | Lib Type | Qty | Source | Total Price ($)
 | C6 | 10n | C_0603_1608Metric |  | Unconfirmed | 0603B103K500NT | FH (Guangdong Fenghua Advanced Tech) | 0603 | 50V 10nF X7R ±10% 0603 Multilayer Ceramic Capacitors MLCC - SMD/SMT ROHS | Multilayer Ceramic Capacitors MLCC - SMD/SMT | 1.The comment (0603B103K500NT) of this part does not match the one (10n) provided in your BOM. Please confirm; | C57112 | https://jlcpcb.com/partdetail/58143-0603B103K500NT/C57112 | Basic | 20 | 20 JLCPCB | 0.046
 | C7,C8 | 1u | C_0603_1608Metric |  | Unconfirmed | CL10A105KB8NNNC | Samsung Electro-Mechanics | 0603 | 50V 1uF X5R ±10% 0603 Multilayer Ceramic Capacitors MLCC - SMD/SMT ROHS | Multilayer Ceramic Capacitors MLCC - SMD/SMT | 1.The comment (CL10A105KB8NNNC) of this part does not match the one (1u) provided in your BOM. Please confirm; | C15849 | https://jlcpcb.com/partdetail/16531-CL10A105KB8NNNC/C15849 | Basic | 20 | 20 JLCPCB | 0.1
C9 |  | 10u | C_1206_3216Metric |  | Unconfirmed | CL31A106KBHNNNE | Samsung Electro-Mechanics | 1206 | 50V 10uF X5R ±10% 1206 Multilayer Ceramic Capacitors MLCC - SMD/SMT ROHS | Multilayer Ceramic Capacitors MLCC - SMD/SMT | 1.The comment (CL31A106KBHNNNE) of this part does not match the one (10u) provided in your BOM. Please confirm; | C13585 | https://jlcpcb.com/partdetail/14236-CL31A106KBHNNNE/C13585 | Basic | 9 | 9 JLCPCB | 0.3024
C10,C17,C19,C16,C1,C15,C18 | C2,C3,C22,C12,C20,C4,C24,C21,C5,C23 | 100n | C_0603_1608Metric |  | Unconfirmed | CC0603KRX7R9BB104 | YAGEO | 0603 | 50V 100nF X7R ±10% 0603 Multilayer Ceramic Capacitors MLCC - SMD/SMT ROHS | Multilayer Ceramic Capacitors MLCC - SMD/SMT | 1.The comment (CC0603KRX7R9BB104) of this part does not match the one (100n) provided in your BOM. Please confirm; | C14663 | https://jlcpcb.com/partdetail/YAGEO-CC0603KRX7R9BB104/C14663 | Basic | 105 | 105 JLCPCB | 0.252
C11 |  | 4.7u | C_1206_3216Metric |  | Unconfirmed | 1206B475K500NT | FH (Guangdong Fenghua Advanced Tech) | 1206 | 50V 4.7uF X7R ±10% 1206 Multilayer Ceramic Capacitors MLCC - SMD/SMT ROHS | Multilayer Ceramic Capacitors MLCC - SMD/SMT | 1.The comment (1206B475K500NT) of this part does not match the one (4.7u) provided in your BOM. Please confirm; | C29823 | https://jlcpcb.com/partdetail/30577-1206B475K500NT/C29823 | Basic | 20 | 20 JLCPCB | 0.666
 | C14,C13 | 22p | C_0402_1005Metric |  | Unconfirmed | C0105C0G220J100NTZ | EYANG(Shenzhen Eyang Tech Development) | 01005 | EYANG(Shenzhen Eyang Tech Development) C0105C0G220J100NTZ |  | 1.The comment (C0105C0G220J100NTZ) of this part does not match the one (22p) provided in your BOM. Please confirm; | C778226 | https://jlcpcb.com/partdetail/826920-C0105C0G220J100NTZ/C778226 | Extended | 20 | 20 JLCPCB | 0.124
D1 |  | 1N5819 | D_MicroMELF |  | Select by Customer | BZM55C5V1 | LGE | MicroMELF | 500mW 5.1V MicroMELF Zener Diodes ROHS | Zener Diodes | 1.The comment (BZM55C5V1) of this part does not match the one (1N5819) provided in your BOM. Please confirm; | C5122136 | https://jlcpcb.com/partdetail/LGE-BZM55C5V1/C5122136 | Extended | 9 | 9 JLCPCB | 0.4743
 | FB1 | FerriteBead | L_0805_2012Metric |  | Select by Customer | BLM21PG221SN1D | Murata Electronics | 0805 | 45mΩ ±25% 220Ω@100MHz 0805 Ferrite Beads ROHS | Ferrite Beads |  | C85840 | https://jlcpcb.com/partdetail/MurataElectronics-BLM21PG221SN1D/C85840 | Extended | 20 | 20 JLCPCB | 0.304
J2 |  | BootConn | PinHeader_2x03_P2.54mm_Vertical |  | Select by Customer | ZX-PZ2.54-2-3PZZ | Megastar | 插件,P=2.54mm | Gold 1kV 3A Direct Insert Policy 2.5mm 6P 6mm -40℃~+105℃ 3mm 2.54mm Brass Double Row Black 2x3P 2.54mm Plugin,P=2.54mm Pin Headers ROHS | Pin Headers |  | C7501274 | https://jlcpcb.com/partdetail/Megastar-ZX_PZ2_54_23PZZ/C7501274 | Extended | 5 | 5 JLCPCB | 0.156
J5 |  | SWD | PinHeader_1x04_P2.54mm_Vertical |  | Select by Customer | PZ254V-11-04P | XFCN | Plugin,P=2.54mm | 250V 3A Direct Insert Policy 2.5mm 4P 6mm -40℃~+105℃ 3mm 2.54mm Single Row Black 1x4P Plugin,P=2.54mm Pin Headers ROHS | Pin Headers |  | C2691448 | https://jlcpcb.com/partdetail/XFCN-PZ254V_1104P/C2691448 | Extended | 6 | 6 JLCPCB | 0.1242
J6 |  | Conn_01x03 | PinHeader_1x03_P2.54mm_Vertical |  | Select by Customer | X6511WV-03H-C60D30 | XKB Connection | 插件,P=2.54mm | Gold 250V 3A Policy 2.5mm 3P 260℃ -40℃~+105℃ 2.54mm Single Row Black Brass 1x3P Plugin,P=2.54mm Pin Headers ROHS | Pin Headers | 1.Multiple lines in the BOM have been matched to the same part. Please check if the matching is correct. ; | C706875 | https://jlcpcb.com/partdetail/XKBConnection-X6511WV_03HC60D30/C706875 | Extended | 13 | 13 JLCPCB | 0.5408
J19 |  | Power_Conn | PinHeader_1x03_P2.54mm_Vertical |  | Select by Customer | X6511WV-03H-C60D30 | XKB Connection | 插件,P=2.54mm | Gold 250V 3A Policy 2.5mm 3P 260℃ -40℃~+105℃ 2.54mm Single Row Black Brass 1x3P Plugin,P=2.54mm Pin Headers ROHS | Pin Headers | 1.Multiple lines in the BOM have been matched to the same part. Please check if the matching is correct. ; | C706875 | https://jlcpcb.com/partdetail/XKBConnection-X6511WV_03HC60D30/C706875 | Extended | 13 | 13 JLCPCB | 0.5408
J7 |  | Gyro_Sensor_ICM_20948_SparkFun_Module | PinSocket_1x06_P2.54mm_Vertical |  | Select by Customer | HB-PH3-25416PB2GOP | Hanbo Electronic | 插件,P=2.54mm | Gold 250V 3A Direct Insert Policy 2.54mm 6P 260℃ 6mm -40℃~+105℃ 3mm 2.54mm Brass Black Single Row 1x6P 2.54mm Plugin,P=2.54mm Pin Headers ROHS | Pin Headers |  | C6332199 | https://jlcpcb.com/partdetail/HanboElectronic-HB_PH325416PB2GOP/C6332199 | Extended | 5 | 5 JLCPCB | 0.1585
J9,J10,J12,J8,J11 | J13,J14,J16,J17,J15 | Conn_01x32 | Hirose_FH12-32S-0.5SH_1x32-1MP_P0.50mm_Horizontal |  | Select by Customer | AFC01-S32FCA-00 | JUSHUO | SMD,P=0.5mm,卧贴 | Flip type 32P Bottom Contact Horizontal attachment 0.5mm SMD,P=0.5mm,Surface Mount，Right Angle FFC, FPC (Flat Flexible) Connector Assemblies ROHS | FFC, FPC (Flat Flexible) Connector Assemblies |  | C262672 | https://jlcpcb.com/partdetail/JUSHUO-AFC01_S32FCA00/C262672 | Extended | 50 | 50 JLCPCB | 7.005
J18 |  | Conn_01x02 | PinHeader_1x02_P2.54mm_Vertical |  | Select by Customer | X6511WV-02H-C60D30 | XKB Connection | 插件,P=2.54mm | Gold 250V 3A Policy 2.5mm 2P 260℃ -40℃~+105℃ 2.54mm Single Row Black Brass 2.54mm 1x2P Plugin,P=2.54mm Pin Headers ROHS | Pin Headers |  | C706874 | https://jlcpcb.com/partdetail/XKBConnection-X6511WV_02HC60D30/C706874 | Extended | 10 | 10 JLCPCB | 0.317
L1 |  | L | L_0805_2012Metric |  | Select by Customer | CBW160808U301T | FH (Guangdong Fenghua Advanced Tech) | 0603 | 300mΩ ±25% 300Ω@100MHz 0603 Ferrite Beads ROHS | Ferrite Beads |  | C139179 | https://jlcpcb.com/partdetail/150500-CBW160808U301T/C139179 | Extended | 20 | 20 JLCPCB | 0.1
P1 |  | USB_C_Plug_USB2.0 | USB_C_Receptacle_Amphenol_12401610E4-2A |  | Select by Customer | 12401610E4#2A | Amphenol ICC | SMD | USB 3.2 1 24P Female Type-C SMD USB Connectors ROHS | USB Connectors |  | C5119948 | https://jlcpcb.com/partdetail/AmphenolICC-12401610E42A/C5119948 | Extended | 5 | 5 JLCPCB | 7.38
R1 |  | 5.1k | R_0603_1608Metric |  | Unconfirmed | 0603WAF5101T5E | UNI-ROYAL(Uniroyal Elec) | 0603 | 100mW Thick Film Resistors 75V ±100ppm/℃ ±1% 5.1kΩ 0603 Chip Resistor - Surface Mount ROHS | Chip Resistor - Surface Mount | 1.The comment (0603WAF5101T5E) of this part does not match the one (5.1k) provided in your BOM. Please confirm; | C23186 | https://jlcpcb.com/partdetail/23913-0603WAF5101T5E/C23186 | Basic | 20 | 20 JLCPCB | 0.02
R4 |  | 330R | R_Axial_DIN0207_L6.3mm_D2.5mm_P7.62mm_Horizontal |  | Select by Customer | MFR50SFTE52-330R | YAGEO | 插件,D2.4xL6.3mm | Metal Film Resistors 330Ω 500mW ±50ppm/℃ ±1% Plugin,D2.4xL6.3mm Through Hole Resistors ROHS | Through Hole Resistors |  | C173152 | https://jlcpcb.com/partdetail/YAGEO-MFR50SFTE52330R/C173152 | Extended | 0 | 0 JLCPCB | 0
R3 | R2 | 10k | R_0603_1608Metric |  | Unconfirmed | 0603WAF1002T5E | UNI-ROYAL(Uniroyal Elec) | 0603 | 100mW Thick Film Resistors 75V ±100ppm/℃ ±1% 10kΩ 0603 Chip Resistor - Surface Mount ROHS | Chip Resistor - Surface Mount | 1.The comment (0603WAF1002T5E) of this part does not match the one (10k) provided in your BOM. Please confirm; | C25804 | https://jlcpcb.com/partdetail/26547-0603WAF1002T5E/C25804 | Basic | 40 | 40 JLCPCB | 0.036
RV1 |  | 500k | Potentiometer_Bourns_3296W_Vertical |  | Select by Customer | 3296W-1-504 | BOCHEN(Chengdu Guosheng Tech) | 插件 | ±10% 500kΩ Plugin Potentiometers, Variable Resistors ROHS | Potentiometers, Variable Resistors |  | C118921 | https://jlcpcb.com/partdetail/120190-3296W_1504/C118921 | Extended | 5 | 5 JLCPCB | 0.8415
SW1 |  | SW_Push | SW_Tactile_SPST_NO_Straight_CK_PTS636Sx25SMTRLFS |  | Select by Customer | TS-1101-C-W | XKB Connection | SMD | None Without 50mA 6mm 50,000 Times 260gf 12V 3.6mm 2.5mm Rectangle button Standing paste SPST SMD Tactile Switches ROHS | Tactile Switches |  | C318938 | https://jlcpcb.com/partdetail/XKBConnection-TS_1101_CW/C318938 | Extended | 6 | 6 JLCPCB | 0.2388
U1 |  | ESP32-C3-Mini | ESP32-C3-Mini-through-hole |  | Unconfirmed | ESP32-C3-MINI-1-N4 | Espressif Systems | SMD,13.2x16.6mm | SMD,13.2x16.6mm RF Modules | RF Modules | 1.The comment (ESP32-C3-MINI-1-N4) of this part does not match the one (ESP32-C3-Mini) provided in your BOM. Please confirm; | C2838502 | https://jlcpcb.com/partdetail/EspressifSystems-ESP32_C3_MINI_1N4/C2838502 | Extended | 0 | 0 JLCPCB | 0
U3 |  | LM358 | SO-8_3.9x4.9mm_P1.27mm |  | Select by System | LM358 | JSMSEMI | SOP-8 | Dual channel 1MHz 5mV SOP-8 Operational Amplifier ROHS | Operational Amplifier |  | C5296727 | https://jlcpcb.com/partdetail/JSMSEMI-LM358/C5296727 | Extended | 5 | 5 JLCPCB | 0.165
U4 |  | STM32F103C8Tx | LQFP-48_7x7mm_P0.5mm |  | Select by System | STM32F103C8T6 | STMicroelectronics | LQFP-48(7x7) | 64KB 2V~3.6V ARM-M3 20KB 72MHz FLASH 37 LQFP-48(7x7) Microcontrollers (MCU/MPU/SOC) ROHS | Microcontrollers (MCU/MPU/SOC) |  | C8734 | https://jlcpcb.com/partdetail/STMicroelectronics-STM32F103C8T6/C8734 | Extended | 5 | 5 JLCPCB | 6.69
U5,U8,U6,U7,U9 | U10,U11,U12,U14,U13 | ADG732BSUZ | TQFP-48_7x7mm_P0.5mm |  | Select by Customer | ADG732BSUZ-REEL | Analog Devices | TQFP-48(7x7) | 5.5Ω 1 TQFP-48(7x7) Analog Switches, Multiplexers ROHS | Analog Switches, Multiplexers | 1.The comment (ADG732BSUZ-REEL) of this part does not match the one (ADG732BSUZ) provided in your BOM. Please confirm; | C114845 | https://jlcpcb.com/partdetail/AnalogDevices-ADG732BSUZREEL/C114845 | Extended | 50 | 50 JLCPCB | 332.55
Y1 |  | 8MHz | Crystal_HC49-4H_Vertical |  | Select by Customer | X49SD8MSD2SC | YXC Crystal Oscillators | HC-49S | 8MHz Through-Hole Crystal Oscillator 20pF ±20ppm ±30ppm HC-49S Crystals ROHS | Crystals |  | C21263 | https://jlcpcb.com/partdetail/YXC_CrystalOscillators-X49SD8MSD2SC/C21263 | Extended | 5 | 5 JLCPCB | 0.3945
U2 |  | FT232RL | SSOP-28_5.3x10.2mm_P0.65mm |  | Select by System | FT232RL | FTDI | SSOP-28-208mil | SSOP-28 USB ICs RoHS | USB ICs |  | C490691 | https://jlcpcb.com/partdetail/FTDI-FT232RL/C490691 | Extended | 5 | 0 JLCPCB | 0

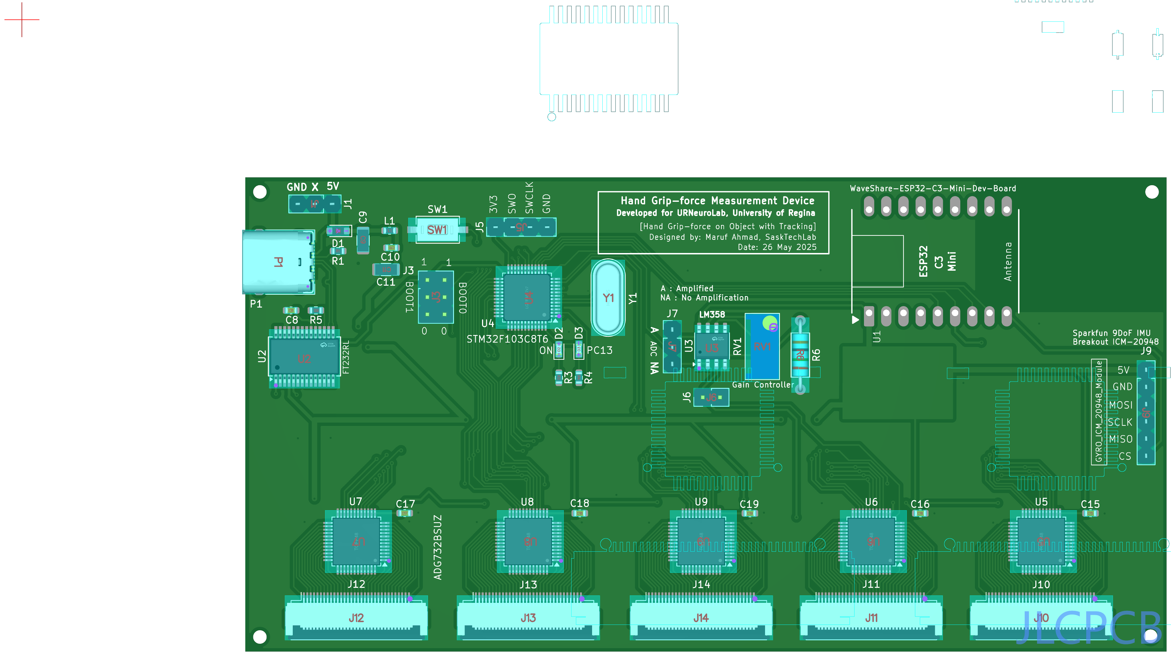
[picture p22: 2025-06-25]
hardware/pcb design/GripForceMeasurementDeviceCkt_STM32F103C8T6/New_BOM_n_CPL/capture-2025-05-30T07_25_52.430Z.png

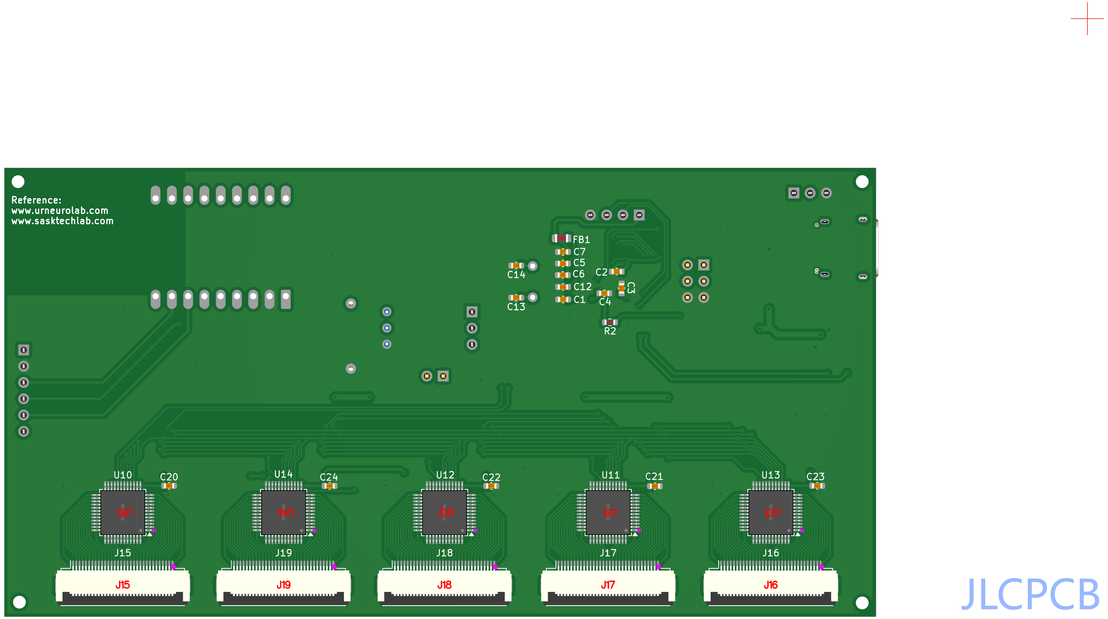
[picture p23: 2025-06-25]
hardware/pcb design/GripForceMeasurementDeviceCkt_STM32F103C8T6/New_BOM_n_CPL/capture-2025-05-30T07_26_32.789Z.png

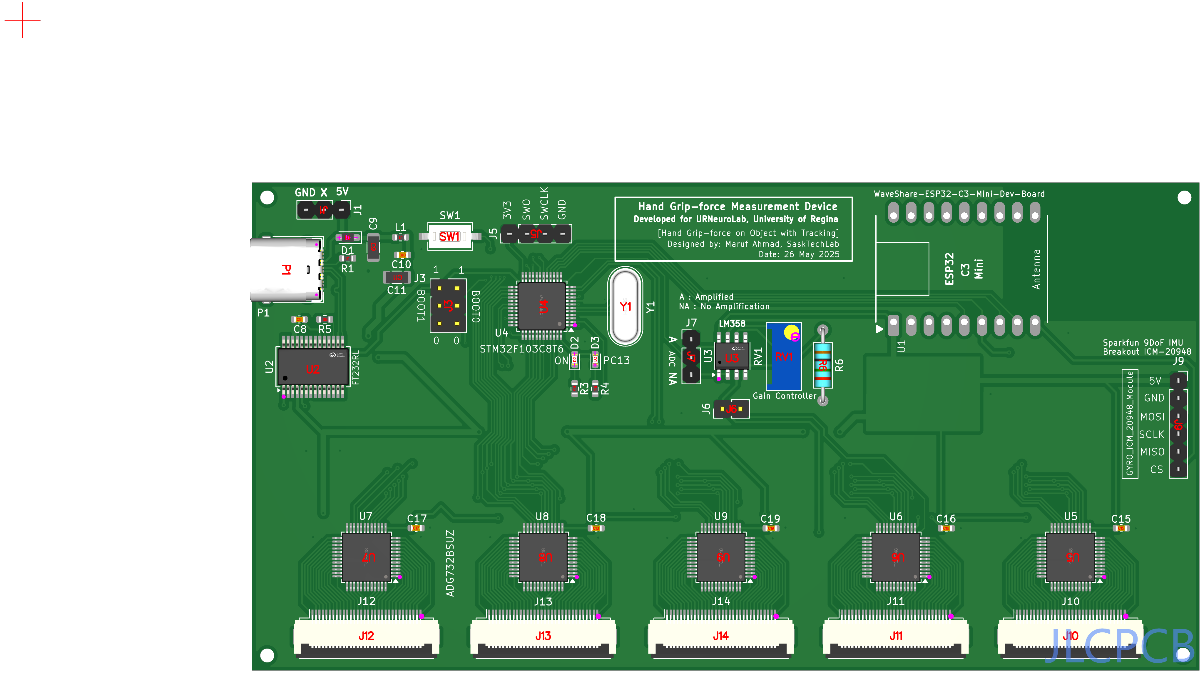
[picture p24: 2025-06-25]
hardware/pcb design/GripForceMeasurementDeviceCkt_STM32F103C8T6/New_BOM_n_CPL/capture-2025-05-30T07_26_22.357Z.png

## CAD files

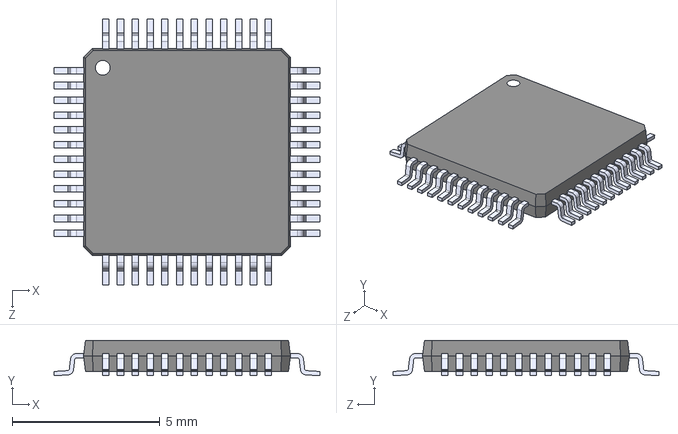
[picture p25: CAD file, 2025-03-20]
components/ADG732BSUZ/ADG732BSUZ.step
9.00 x 1.20 x 9.00 mm

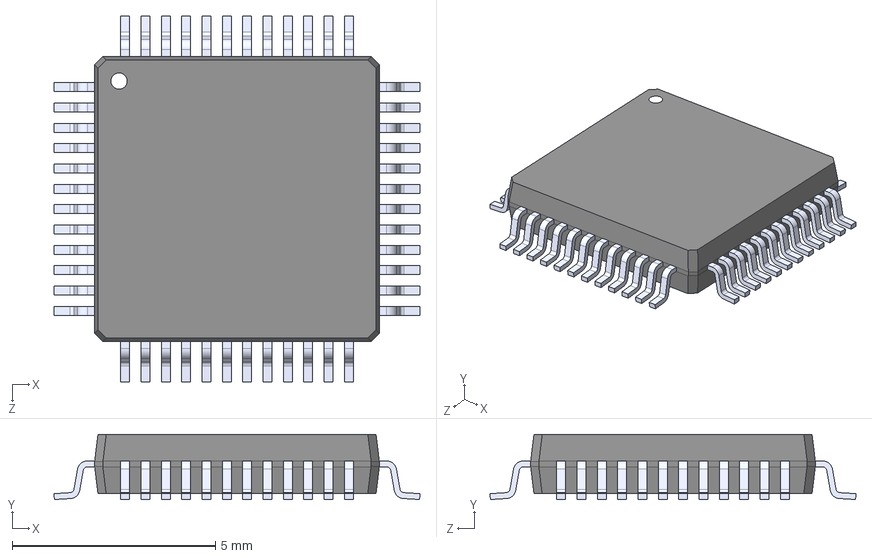
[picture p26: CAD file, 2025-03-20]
components/STM32F103C8T6/STM32F103C8T6.step
9.00 x 1.60 x 9.00 mm

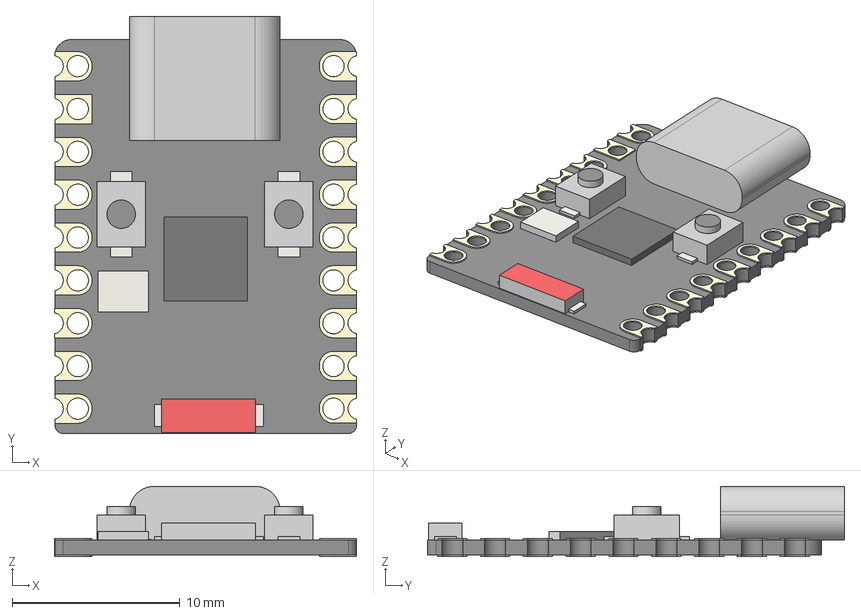
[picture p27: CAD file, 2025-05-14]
hardware/pcb design/3D-Models-Step-files/Waveshare ESP32-C3 Zero.step
18.0 x 24.9 x 4.20 mm
PCB
USB Type-C
SoC
BOOT
RESET
Crystal
Antenna

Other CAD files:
hardware/pcb design/3D-Models-Step-files/Waveshare ESP32-C3 Zero.f3d

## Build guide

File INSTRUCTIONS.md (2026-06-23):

# GripForce Measurement Device - Project Instructions

Last Updated: June 22, 2026

---

## 1. Project Overview

This is a comprehensive **hand grip force and object trajectory measurement system** designed for clinical and research applications, particularly for **neurological assessment** of patients with **stroke** or **Multiple Sclerosis (MS)**.

The system combines:
- **Pressure sensing** (32×64 grid, 2048 spatial samples)
- **IMU tracking** (Gyroscope, Accelerometer, Magnetometer)
- **Vision-based pose estimation** (AprilTag detection for 4K video)
- **Real-time visualization** (Python visualizers + web-based 3D viewer)
- **Data logging and playback** (NDJSON pressure/IMU sessions, viewer data export)

---

## 2. Main Purpose

**Objective**: Enable clinicians and researchers to:
- Quantitatively assess **hand grip strength and control** during task execution
- Track and visualize **object movement and orientation** in real-time
- Analyze **neuromuscular impairments** and rehabilitation outcomes
- Record and replay synchronized pressure, IMU, and video data

**Use Cases**:
- Stroke recovery evaluation (motor control assessment)
- MS patient monitoring (grip strength trends)
- Hand rehabilitation research
- Biomechanical analysis of gripping tasks

---

## 3. Current App Features

### Pressure Distribution Visualization
- **32×64 heatmap** of grip force across sensor pad
- Real-time animated pressure overlay with configurable colormap (default: rainbow)
- Pressure range: 0–4095 (raw ADC counts)
- Automatic or manual color scaling (VMIN/VMAX)
- Supports **flipped**, **rotated**, and **half-mirror** transformations for sensor orientation

### IMU Data Visualization
- **Gyroscope**: angular velocity (°/s) at ±250 dps range
- **Accelerometer**: linear acceleration (g) at ±2 g range
- **Magnetometer**: magnetic field (µT) AK09916 sensor (0.15 µT/LSB)
- Real-time animated plots with configurable sliding window (default: 800 samples)
- Optional magnitude-only view (single trace per sensor)
- Per-component plots (X, Y, Z channels)

### 3D Visualization Options
- Optional **3D cylinder object** rendered to match object orientation (from IMU rotation matrix)
- Interactive 3D view with matplotlib 3D axes
- Real-time quaternion-to-matrix conversion

### Data Logging
- Optional **NDJSON session recording** (one JSON object per line)
- Logs all pressure frames and IMU data with timestamps
- Supports replay in web viewer for later analysis

### 3D Simulator
- Realistic **moving pressure patterns** (circular blob with velocity)
- Simulated IMU data (smooth gyro/accel/mag oscillations)
- No hardware required for testing and development
- Interactive GUI option available

### Web Viewer & AprilTag Export
- **Standalone desktop viewer** (via pywebview) or browser
- AprilTag-based **4K video pose detection** and annotation
- Exports **viewer_data.json** and **viewer.html** with embedded annotated frame data
- Supports **start/end frame selection** for video processing
- Video resizing for browser optimization (720p, 360p, 240p variants)

---

## 4. Important Files and What Each Does

### Core Visualizer Scripts (`app/device_data_acquisitiom/`)

| File | Purpose |
|---|---|
| `viz_full_with_gyro_accel_mag.py` | Standard 2D visualizer: pressure heatmap + IMU plots |
| `viz_full_with_gyro_accel_mag_3Dobj.py` | Enhanced 2D visualizer + optional 3D cylinder object |
| `simulator.py` | Simulates realistic pressure/IMU data without hardware |
| `simulator_gui.py` | Interactive GUI for simulator (if available) |
| `run_viz_app.bat` | Batch launcher for standard visualizer |
| `run_viz_3D.bat` | Batch launcher for 3D visualizer |

### Viewer & Pose Estimation (`app/device_pose_acquisition/auto_target_detections/`)

| File | Purpose |
|---|---|
| `detect_apriltag_pose_fixed11_4k.py` | Primary AprilTag detector for 4K video; exports viewer data |
| `viewer_7371/viewer.html` | Web-based viewer template (portable, self-contained) |
| `viewer_7371/viewer_data.json` | Exported frame data (sanitized numerics) |
| `viewer_7371/standalone_viewer.py` | Desktop launcher for viewer.html via pywebview |
| `run_viewer_standalone.bat` | Batch launcher for desktop viewer |

### Session Data (`app/device_pose_acquisition/4k_video_process/sessions/`)

| File | Purpose |
|---|---|
| `session1.ndjson`, `session_2.ndjson` | Recorded pressure + IMU frames (NDJSON format) |

### Hardware & Firmware

| File | Purpose |
|---|---|
| `firmware/esp32/ESP32_C3_Zero_SPI_2048_UDP.ino` | ESP32 firmware: SPI slave, UDP broadcaster |
| `firmware/stm32f103c8t6/Core/Src/main.c` | STM32 firmware: scans 32×64 matrix via ADG732 multiplexers |
| `firmware/stm32f103c8t6/Drivers/...` | STM32 HAL and CMSIS libraries |

### Documentation

| File | Purpose |
|---|---|
| `docs/System_Protocol_and_Wiring.md` | Pinouts, SPI/UDP frames, endianness, timing |
| `hardware/README.md` | KiCad project, BOM, component references |
| `hardware/pcb design/GripForceMeasurementDeviceCkt_STM32F103C8T6/` | KiCad schematics and board layout |

---

## 5. Data Formats

### 5.1 Pressure Data Format

**Source**: ESP32 reads 2048 uint16 values via SPI from STM32, then broadcasts over UDP

**UDP Frame Structure** (415 bytes per packet):
```
[0]      0xAA               (start marker)
[1]      0x55               (start marker)
[2]      chunk_index        (0–9, indicating position in frame)
[3..412] 410 bytes          (205 × uint16 values, LSB first per value)
[413]    0x55               (end marker)
[414]    0xAA               (end marker)
```

**Per-Frame Assembly**:
- 10 UDP packets (indices 0–9) concatenated in order
- Total: 2050 values; visualizer uses first **2048 values**
- Reshape as **32 (rows) × 64 (columns)** matrix

**Data Type**: `uint16`, little-endian
**Range**: 0–4095 (raw 12-bit ADC)
**Update Rate**: ~60 fps (adjustable via firmware delay)

**Default UDP Endpoint**: `0.0.0.0:12345`

---

### 5.2 IMU Data Format

**Source**: ESP32 reads ICM-20948 sensor (6-pin module) via SPI

**Packet Header**: `b'\xAA\x55IM'` (4 bytes) + data

**Data Structure (22 bytes total)**:
- 9 × `int16` (big-endian) for: Gyro(X,Y,Z) + Accel(X,Y,Z) + Mag(X,Y,Z)

**Scale Factors**:
| Sensor | Range | LSB | Units |
|---|---|-----|---|
| Gyro | ±250 dps | 131.0 | deg/s |
| Accel | ±2 g | 16384.0 | g |
| Mag | ±120 µT | 0.15 | µT |

**Fallback Header** (if mag unavailable): `b'\xAA\x55GY'` (16 bytes, no magnetometer)

---

### 5.3 Viewer Data Format (JSON Export)

**Purpose**: Portable frame and annotation data for web viewer

**Structure**:
```json
{
  "frames": [
    {
      "frame_idx": 0,
      "timestamp_ms": 1234567890,
      "circles": [
        {"x_px": 100, "y_px": 200, "radius_px": 20, "label": "A"}
      ],
      "detections": [
        {"x": 10.5, "y": 20.3, "z": 5.1, "rx": 0.1, "ry": 0.2, "rz": 0.3}
      ]
    }
  ],
  "meta": {"video_fps": 30, "total_frames": 150}
}
```

**Generated By**: `detect_apriltag_pose_fixed11_4k.py --export-viewer-data <path>`

**Outputs**:
- `viewer_data.json` — sanitized numeric data
- `viewer.html` — self-contained HTML with embedded data

---

### 5.4 Session Data Format (NDJSON)

**Purpose**: Streaming-safe pressure + IMU recording for replay

**Format**: One JSON object per line (newline-delimited)

**Metadata Line**:
```json
{
  "type": "meta",
  "schema": "kinesiology.pressure_imu.ndjson.v1",
  "created_unix_s": 1781914344.1745646,
  "frame_shape": [32, 64],
  "pressure_dtype": "uint16",
  "pressure_layout": "row-major-flat",
  "imu_units": {"gyro": "deg_s", "accel": "g", "mag": "uT"}
}
```

**Frame Line** (repeating):
```json
{
  "type": "frame",
  "frame_idx": 0,
  "t_rel_s": 0.8313055038452148,
  "t_unix_s": 1781914345.0028675,
  "pressure_u16_flat": [0, 0, 6, 25, 11, 5, ...],
  "gyro_deg_s": [50.0, 30.0, 20.0],
  "accel_g": [0.1, 0.05, 1.0],
  "mag_uT": [40.0, 40.0, 30.0]
}
```

**Used By**: Web viewer for replay, analysis tools

---

### 5.5 Video & Annotation Formats

**Input**: 4K MP4 (e.g., `IMG_0005.MOV`, typically 60 fps)

**Processing**: AprilTag detection extracts 3D pose per frame

**Output**: 
- Annotated MP4 with overlaid circles/detections
- Resized variants (720p, 360p, 240p) for web playback
- Viewer HTML with frame-by-frame data

**FFmpeg Resize Commands** (stored in Note.txt):
```bash
# 720p
ffmpeg -y -i input.mp4 -vf "scale=1280:-2" -c:v libx264 ... output_720p.mp4

# 360p, 15fps
ffmpeg -y -i input.mp4 -vf "fps=15,scale=-2:360" -c:v libx264 ... output_360p_15fps.mp4
```

---

## 6. Important Rules for Future Editing

### 6.1 Do Not Delete or Simplify Features

- **Pressure distribution sensor ratio must stay fixed at 32 × 64**
- **Do not remove IMU support** (gyro, accel, mag)
- **Preserve older project functionality** when fixing bugs
- Do not simplify AprilTag viewer workflow
- Keep all batch launcher files (`.bat`) for user convenience

### 6.2 Heatmap & UI Constraints

- **Heatmap should resize correctly without stretching or squeezing**
  - Maintain aspect ratio; use proper matplotlib grid layout
- **Pressure distribution panel should show heatmap and controls without unnecessary scrolling**
  - Use GridSpec to balance plot sizes
- **Color mapping should be configurable** without code changes (VMIN, VMAX, colormap)

### 6.3 Data Synchronization

- **Video, pressure data, and viewer/pose data should stay synchronized**
  - Use Unix timestamps (`t_unix_s`) for alignment
  - Maintain frame index (`frame_idx`) continuity
- **Bug fixes should be minimal and should not break other panels**
  - Test all visualizer panels after edits
  - Preserve UDP packet format (10 packets per frame, 415 bytes each)

### 6.4 Configuration & Defaults

- **Default UDP endpoint**: `0.0.0.0:12345`
- **Default simulator IP/port**: `127.0.0.1:12345`
- **Default frame size**: 32 rows × 64 columns
- **Default pressure range**: 0–4095
- **Default IMU scales**: Gyro 131.0, Accel 16384.0, Mag 0.15
- **Do not change these without updating documentation and all dependent scripts**

### 6.5 Version Control

- Keep `.gitignore` as-is (ignores `*.mp4`, `*.pyc`, `__pycache__/`, etc.)
- Commit changes with descriptive messages
- Tag releases with version numbers

---

## 7. Known Issues

### Needs Confirmation (Not Fully Tested)

| Issue | Impact | Status |
|---|---|---|
| Video resolution auto-scaling in AprilTag detector | Low | Unconfirmed |
| Magnetometer availability fallback (`GY` vs `IM` headers) | Low | Unconfirmed |
| Multi-monitor layout for visualizer | Low | Unconfirmed |
| Very large session files (>1GB NDJSON) | Medium | Unconfirmed |

### Potential Improvements (No Bugs Reported)

- Web viewer performance with large datasets (>10,000 frames)
- Pressure sensor drift calibration over long sessions
- Bluetooth stability on Windows 10/11

---

## 8. Development / Run Instructions

### 8.1 Quick Start (Windows CMD)

**Simulator (No Hardware)**:
```bash
cd app\device_data_acquisitiom
python simulator.py --ip 127.0.0.1 --port 12345 --fps 60
```

**Start Visualizer** (in separate terminal):
```bash
cd app\device_data_acquisitiom
python viz_full_with_gyro_accel_mag.py --ip 0.0.0.0 --port 12345 --show-magnitude
```

Or use batch files:
```bash
run_viz_app.bat       # Standard visualizer
run_viz_3D.bat        # 3D visualizer with cylinder
run_viewer_standalone.bat  # Web viewer (desktop)
```

### 8.2 With Hardware (ESP32 + STM32 + Sensor Pad)

1. **Program ESP32** with `firmware/esp32/ESP32_C3_Zero_SPI_2048_UDP.ino`
   - Set `udpAddress` to your PC's IP
   - Set `udpPort = 12345` (or custom)
   - Configure WiFi SSID/password

2. **Program STM32F103C8T6** with firmware from `firmware/stm32f103c8t6/`
   - Use STM32CubeProgrammer
   - Or compile in STM32CubeIDE and program via JTAG

3. **Connect sensor pad** to STM32 ADG732 multiplexer chain
   - Verify pinouts in `docs/System_Protocol_and_Wiring.md`

4. **Start visualizer**:
   ```bash
   python viz_full_with_gyro_accel_mag.py --ip 0.0.0.0 --port 12345 --show-magnitude
   ```

### 8.3 AprilTag Video Processing

**Basic Usage**:
```bash
cd app\device_pose_acquisition\auto_target_detections
python detect_apriltag_pose_fixed11_4k.py --video input.mp4 --annotated-out output.mp4
```

**With Viewer Export**:
```bash
python detect_apriltag_pose_fixed11_4k.py \
  --video input.mp4 \
  --annotated-out output.mp4 \
  --export-viewer-data viewer_folder \
  --process-fps 15 \
  --max-frames 0
```

**Optional Parameters**:
- `--start-frame N` — start processing at frame N
- `--end-frame N` — stop at frame N
- `--undistort` — apply camera distortion correction
- `--max-frames N` — process max N frames (0 = all)

### 8.4 Install Python Dependencies

```bash
python -m pip install -r requirements.txt
```

**Key packages**:
- `numpy`, `scipy`
- `matplotlib` (for 2D/3D plotting)
- `opencv-python` (for video/image processing)
- `pupil-apriltags` (for AprilTag detection)
- `pywebview` (for standalone viewer)

---

## 9. Future Work

### Short-term (Next 1–3 Months)

- [ ] **Calibration UI**: Interactive pressure sensor calibration wizard
- [ ] **Real-time statistics panel**: Live grip strength metrics (max, mean, duration)
- [ ] **Patient profile system**: Save/load patient settings and historical data
- [ ] **Session playback controls**: Play, pause, slow-motion for recorded NDJSON

### Medium-term (3–6 Months)

- [ ] **Cloud storage integration**: Upload sessions to cloud for remote analysis
- [ ] **Batch video processing**: Queue multiple videos for AprilTag detection
- [ ] **Advanced analytics dashboard**: Trend analysis, comparison across sessions
- [ ] **Mobile app MVP**: Lightweight grip strength monitoring on Android/iOS

### Long-term (6+ Months)

- [ ] **AI-based grip classification**: ML model for detecting grip patterns (pinch, power, etc.)
- [ ] **Multi-patient database**: Centralized data management with role-based access
- [ ] **Integration with EHR systems**: Export data to hospital databases
- [ ] **Predictive rehabilitation model**: ML-based recovery outcome prediction

---

## 10. Needs Confirmation

### Questions for the User

1. **Screenshot / Screenshots**:
   - A new screenshot `new_gripforce_3dsimulator_outlook.png` exists in `app/`. Should it be featured prominently in README?
   - Are there other screenshots or demo videos you'd like to add?

2. **Demonstration Video**:
   - A new video URL was provided: `https://www.youtube.com/watch?v=0S4J9DHq-p0`
   - What is this video about? (GripForce 3D viewer demo? New features? User workflow?)
   - Should it be the primary video, or kept alongside the existing AprilTag video?

3. **Web Viewer Path**:
   - Is `web_viz_app/` a typo in app/README.md, or does this folder exist elsewhere?
   - Should references be updated to `device_pose_acquisition/auto_target_detections/viewer_7371/`?

4. **Session Data Location**:
   - Sessions are stored in `app/device_pose_acquisition/4k_video_process/sessions/`
   - Should users be able to upload/download sessions? Is cloud storage planned?

5. **Calibration & Sensor Drift**:
   - Is pressure sensor calibration a known issue? Should it be documented?
   - Are there any reference measurements or known sensor limitations?

6. **Performance Targets**:
   - What is the target frame rate? (Currently ~60 fps, documented as adjustable)
   - What is the maximum session duration before performance degrades?

7. **Hardware Variants**:
   - Are there other MCU variants beyond STM32F103C8T6 and ESP32-C3?
   - Should this project support modular hardware swapping?

8. **Export Formats**:
   - Should CSV export be supported (in addition to NDJSON)?
   - What are the preferred formats for clinical reports?

---

## Revision History

| Date | Version | Changes |
|---|---|---|
| 2026-06-22 | 1.0 | Initial comprehensive documentation |

---

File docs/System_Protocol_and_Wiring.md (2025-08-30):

# System Protocol and Wiring

This document captures the exact data framing, pin mappings, and communication settings between the STM32F103C8T6 scanner MCU and the ESP32‑C3 transport, plus notes for the PC visualizer.

## Overview

- Sensor matrix: 32 rows × 64 columns (2048 samples per frame)
- Scanner: STM32F103C8T6 reads the matrix via ADG732 analog multiplexers into ADC1 (PA0)
- Transport: ESP32‑C3 (master) reads frames over SPI from the STM32 (slave) and broadcasts over UDP
- Visualizer: Python script (`software/viz_full_4.py`) assembles 10 UDP chunks into a 32×64 frame

## Data flow and timing

1) STM32 continuously scans the 32×64 matrix into a double buffer in RAM
- Buffer shape: uint16[32][64] (little‑endian in memory)
- Scan timing: address select → delay_us(DELAY_MicroSec) → ADC read (ADC1_IN0)
- Default delay: `#define DELAY_MicroSec 10`

2) ESP32 performs one SPI burst read per frame
- Reads 2048 × 16‑bit words using 2048 calls to `SPI.transfer16(0x0000)`
- SPI transaction speed for frame: 400 kHz, MSB first, MODE 0
- Chip Select is asserted low for the whole burst

3) ESP32 sends the frame in 10 UDP packets
- Each packet carries 205 values (205×2 = 410 bytes) with start/end markers
- 10 chunks → 2050 values; visualizer uses the first 2048 to form a frame

## SPI link details (ESP32 master → STM32 slave)

- Mode: SPI Mode 0 (CPOL=0, CPHA=0)
- Bit order: MSB first on ESP32
- Word size on STM32: 8‑bit (HAL config), bytes stream out in memory order
- Clock: 400 kHz for frame reads (IMU test uses 4 MHz on same bus with a different CS)
- Transaction length: 4096 bytes per frame (2048 × uint16)
- Burst framing: ESP32 asserts CS low before the burst and high after

Endianness note:
- STM32 stores uint16 in little‑endian; HAL SPI streams low byte then high byte from memory
- ESP32 `transfer16` with MSB first assembles a 16‑bit word with the first received byte as MSB
- The PC visualizer auto‑detects endianness; recommended setting is little‑endian (LE)

## UDP frame format (ESP32 → PC)

Per‑packet payload is 415 bytes:
- [0]  0xAA
- [1]  0x55
- [2]  chunk_index in 0..9
- [3..412] 410 bytes = 205 × uint16 values (LSB first per value)
- [413] 0x55
- [414] 0xAA

Per‑frame:
- 10 packets (indices 0..9). Concatenate in index order; take first 2048 values → reshape 32×64
- Default UDP dest: IP set in `firmware/esp32/ESP32_C3_Zero_SPI_2048_UDP.ino` via `udpAddress`, port 12345
- Visualizer bind defaults: `--ip 0.0.0.0 --port 12345` (overridable)

## ESP32‑C3 pins (Waveshare ESP32‑C3 Zero style)

Defined in `firmware/esp32/ESP32_C3_Zero_SPI_2048_UDP.ino`:
- SPI SCK: GPIO 2 (`PIN_CLK`)
- SPI MISO: GPIO 3 (`PIN_MISO`)
- SPI MOSI: GPIO 4 (`PIN_MOSI`)
- STM32 CS/NSS: GPIO 1 (`PIN_CS`)
- IMU CS (ICM‑20948 module): GPIO 5 (`PIN_IMU_CS`)

Wi‑Fi/UDP:
- SSID: `uofrGuest` (password empty) [edit as needed]
- UDP destination: `udpAddress` (your PC’s IP), `udpPort = 12345`

SPI transactions on ESP32:
- Frame read: `SPI.beginTransaction(SPISettings(400000, MSBFIRST, SPI_MODE0))`
- IMU WHO_AM_I read (same bus): `SPISettings(4000000, MSBFIRST, SPI_MODE0)` with CS on GPIO 5

## STM32F103C8T6 pins and peripherals

SPI1 (slave) – from `Core/Src/stm32f1xx_hal_msp.c`:
- NSS:  PA4 (input)
- SCK:  PA5 (input)
- MISO: PA6 (AF push‑pull output)
- MOSI: PA7 (input)

ADC1:
- Channel: ADC1_IN0 on PA0 (analog)
- Sampling time: 1.5 cycles (CubeMX init); conversions triggered in software

UART1 (debug/log):
- TX: PA9, RX: PA10
- CubeMX default baud: 115200; custom `USART1_Init()` sets 921600 (8N1)

GPIOs to ADG732 multiplexers (control and enables) – defined in `Core/Src/main.c`:
- Address lines (A0..A4) on GPIOB:
  - A0 = PB4, A1 = PB3, A2 = PB15, A3 = PB14, A4 = PB13
- Write and enable strobes on GPIOB:
  - WR = PB10, EN = PB1 (active‑low enable logic in code; default EN reset)
- Row side selects:
  - ROW_SEL_L = PB8, ROW_SEL_R = PB9
- Column enable selects (Left half):
  - CON_SEL_L_1 = PB11, CON_SEL_L_2 = PB12, CON_SEL_L_3 = PB6, CON_SEL_L_4 = PA1
- Column enable selects (Right half):
  - CON_SEL_R_1 = PB0, CON_SEL_R_2 = PB5, CON_SEL_R_3 = PB7, CON_SEL_R_4 = PA2

These pins are initialized in `ADG732_Init()` with GPIOB and GPIOA clocks enabled.

Row/column mapping helpers:
- Columns are remapped with `MapColumnIndex(col)` to hardware order (handles mixed wiring)
- Rows use `MapRowAddrForSide(row, col)` inside `ADG732_SelectChannel2()` to compute the ADG732 row address per half (left/right)

Scanning sequence (per sample):
1) Assert appropriate ROW side (left/right), set mapped row address, strobe WR
2) Set column address, strobe WR
3) Assert the single column‑enable for the current side and row‑group (8‑row groups)
4) Delay `DELAY_MicroSec` and read ADC1

## Double‑buffered SPI streaming (STM32)

- Two frame buffers: `bufA`, `bufB` (uint16[32][64])
- ISR (`HAL_SPI_TxRxCpltCallback`): re‑arms SPI immediately; swaps TX/fill buffers only when `frame_ready` is set by the scanner loop
- Main loop: continuously scans into the fill buffer and then sets `frame_ready = 1`
- SPI is configured as 8‑bit 2‑line slave with NSS hardware input; TX length per burst is 4096 bytes

## Visualizer expectations

- Binds UDP on configurable IP/port (defaults `0.0.0.0:12345`)
- Accepts 415‑byte packets described above; assembles 10 chunks into a frame
- Endianness auto‑detected from plausible ranges (0..4095). You can force LE/BE inside `viz_full_4.py`
- Optional geometry fixes: the script can mirror each 32‑column half independently to match physical layout

## Wiring summary (inter‑board)

ESP32‑C3 ↔ STM32F103C8T6 SPI:
- ESP32 GPIO2 (SCK) → STM32 PA5 (SPI1_SCK)
- ESP32 GPIO3 (MISO) ← STM32 PA6 (SPI1_MISO)
- ESP32 GPIO4 (MOSI) → STM32 PA7 (SPI1_MOSI)
- ESP32 GPIO1 (CS)   → STM32 PA4 (SPI1_NSS)
  - Shared ground and 3V3 compatible logic levels required

ESP32‑C3 ↔ IMU (ICM‑20948 module):
- Shared SCK/MISO/MOSI; dedicated CS on ESP32 GPIO5

STM32F103C8T6 → Sensor matrix:
- ADC input: PA0
- ADG732 address/control/enable pins as listed above to drive row/column selection

## Known defaults

- System clock: 72 MHz (HSE ×9)
- ADC align: right; single conversion, software trigger
- UART: 921600 8N1 in user init; 115200 in CubeMX init (user code overrides)
- Visualizer port: 12345; ESP32 sends to `udpAddress` configured in the sketch

## Quick checks

- If the picture looks byte‑swapped, set `ENDIAN_MODE = "LE"` in `viz_full_4.py`
- If halves are mirrored, toggle `APPLY_HALF_MIRROR` in `viz_full_4.py`
- Ensure ESP32 `udpAddress` is your PC’s IP and firewall allows UDP on the chosen port

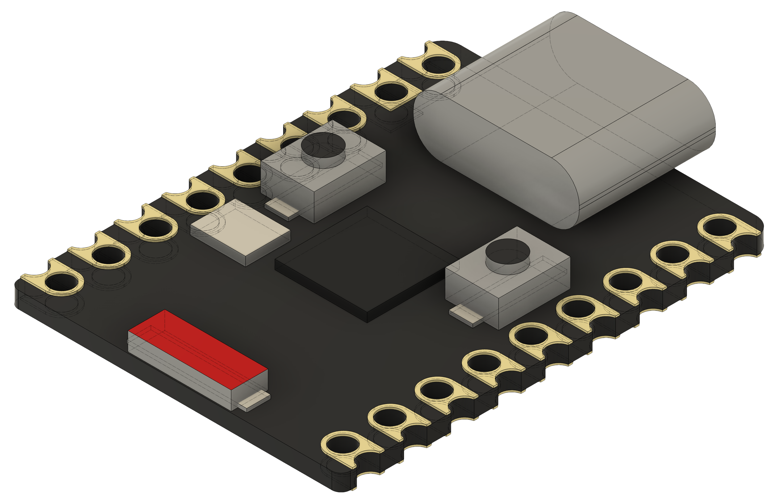
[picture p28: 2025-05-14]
hardware/pcb design/3D-Models-Step-files/Waveshare ESP32-C3 Zero.png

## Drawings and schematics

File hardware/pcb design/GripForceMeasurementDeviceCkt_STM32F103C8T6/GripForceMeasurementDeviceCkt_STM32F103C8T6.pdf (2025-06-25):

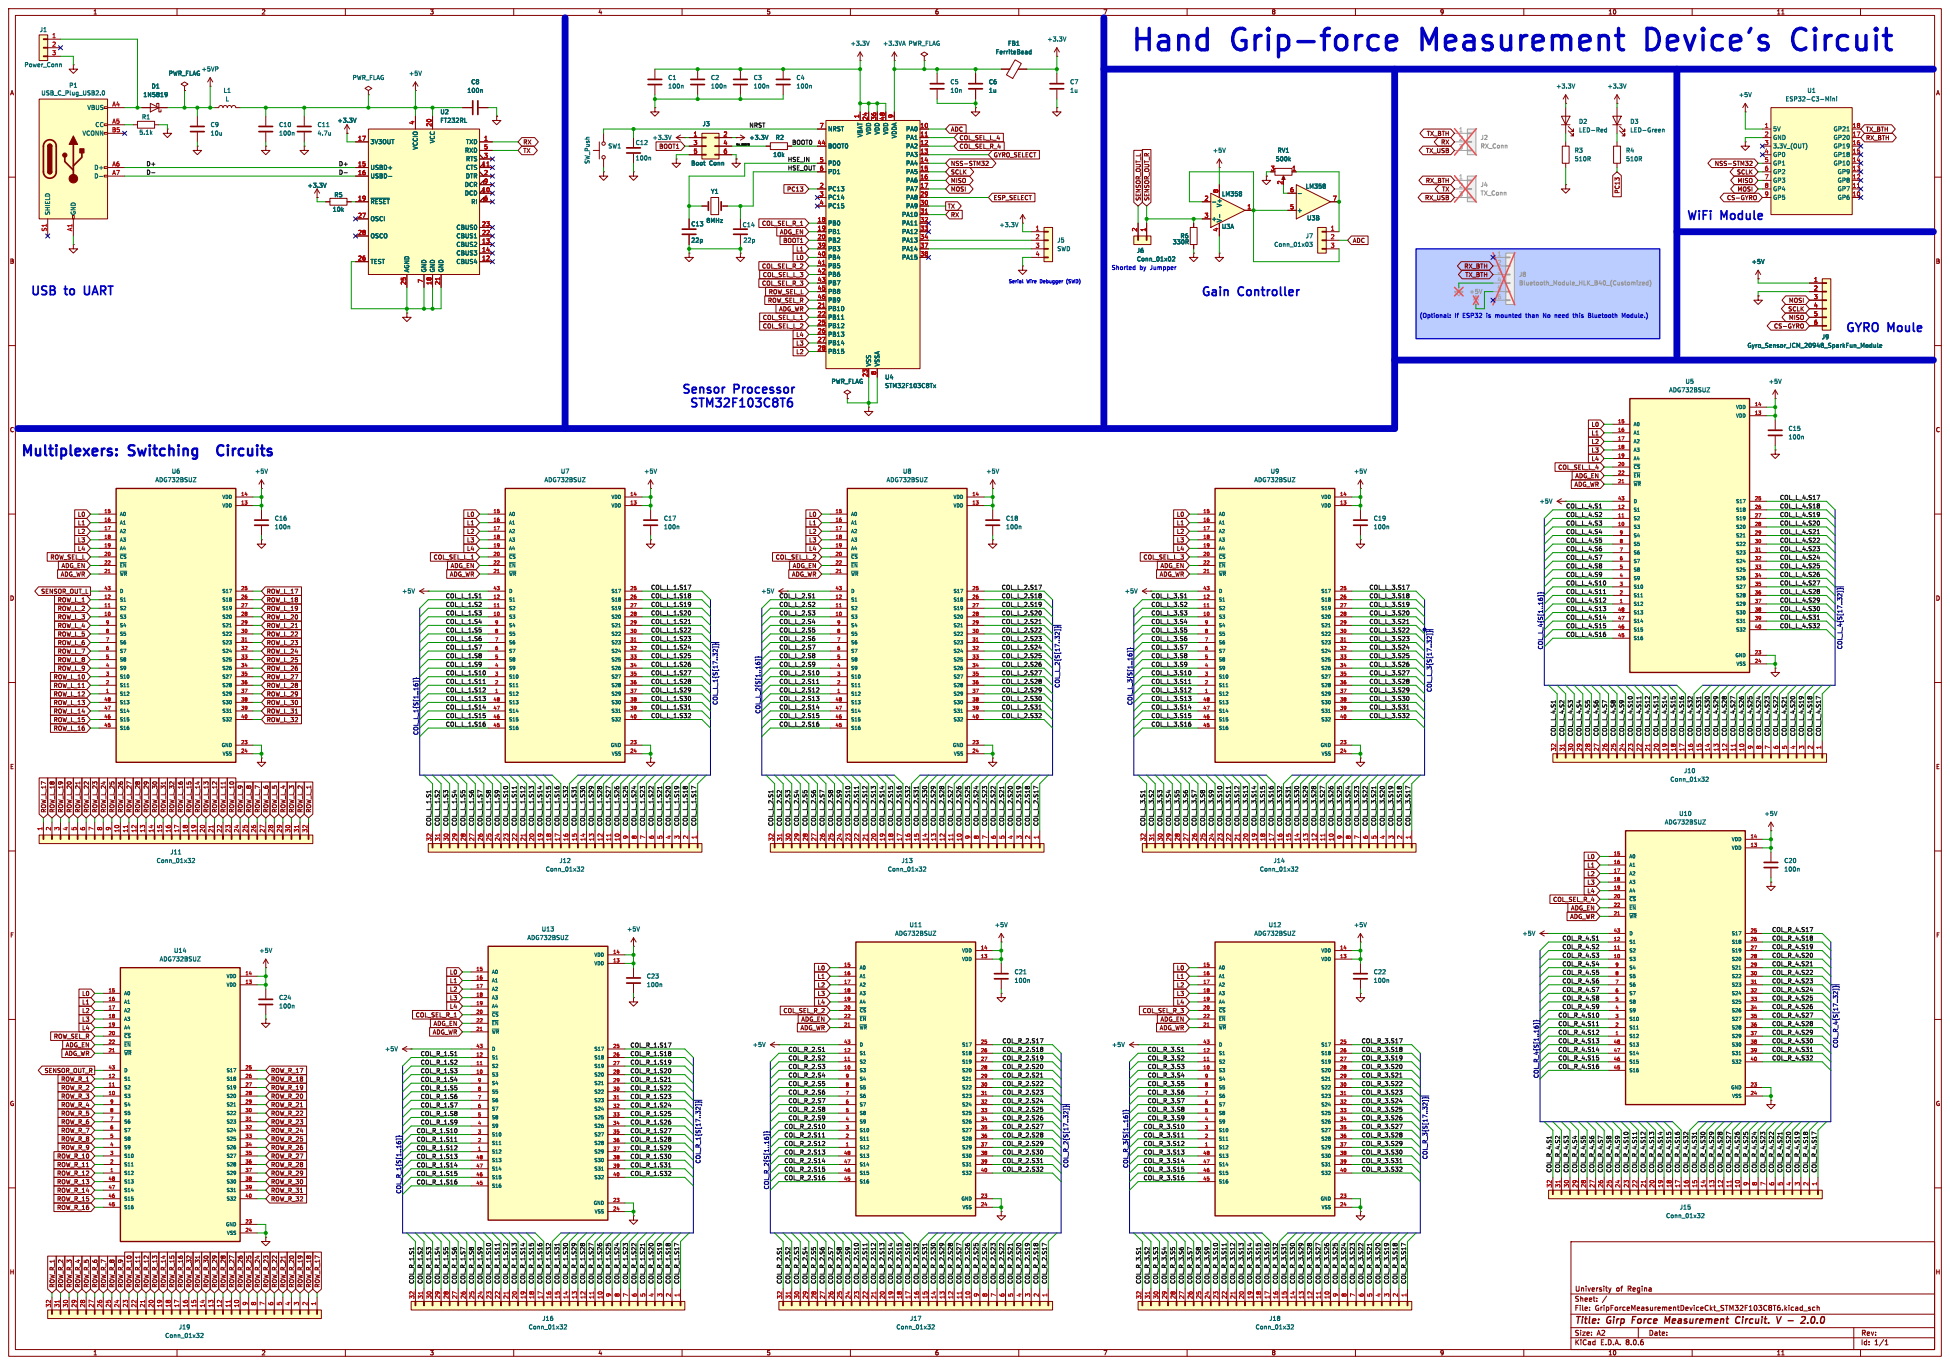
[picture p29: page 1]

U2 FT232RLTXD 1 DCD 10 CTS 11 CBUS4 12 CBUS2 13 CBUS3 14 USBD+ 15 USBD- 16

1 PA0 10 PA1 11 PA2 12 PA3 13 PA4 14 PA5 15 PA6 16 PA7 17 PB0 18 PB1 19 PC13 2 PB2 20 PB10 21 PB11 22 VSS 23 VDD 24 PB12 25 PB13 26 PB14 27 PB15 28 PA8 29 PC14 3 PA9 30 PA10 31 PA11 32 PA12 33 PA13 34 VDD 36 PA14 37 PA15 38 PB3 39 PC15 4 PB4 40 PB5 41 PB6 42 PB7 43 BOOT0 44 PB8 45 PB9 46 VDD 48 PD0 5 PD1 6 NRST 7 VSSA

TXD 1 DCD 10 CTS 11 CBUS4 12 CBUS2 13 CBUS3 14 USBD+ 15 USBD- 16

CS-GYRO MOSI NSS-STM32 COL_SEL_R_2

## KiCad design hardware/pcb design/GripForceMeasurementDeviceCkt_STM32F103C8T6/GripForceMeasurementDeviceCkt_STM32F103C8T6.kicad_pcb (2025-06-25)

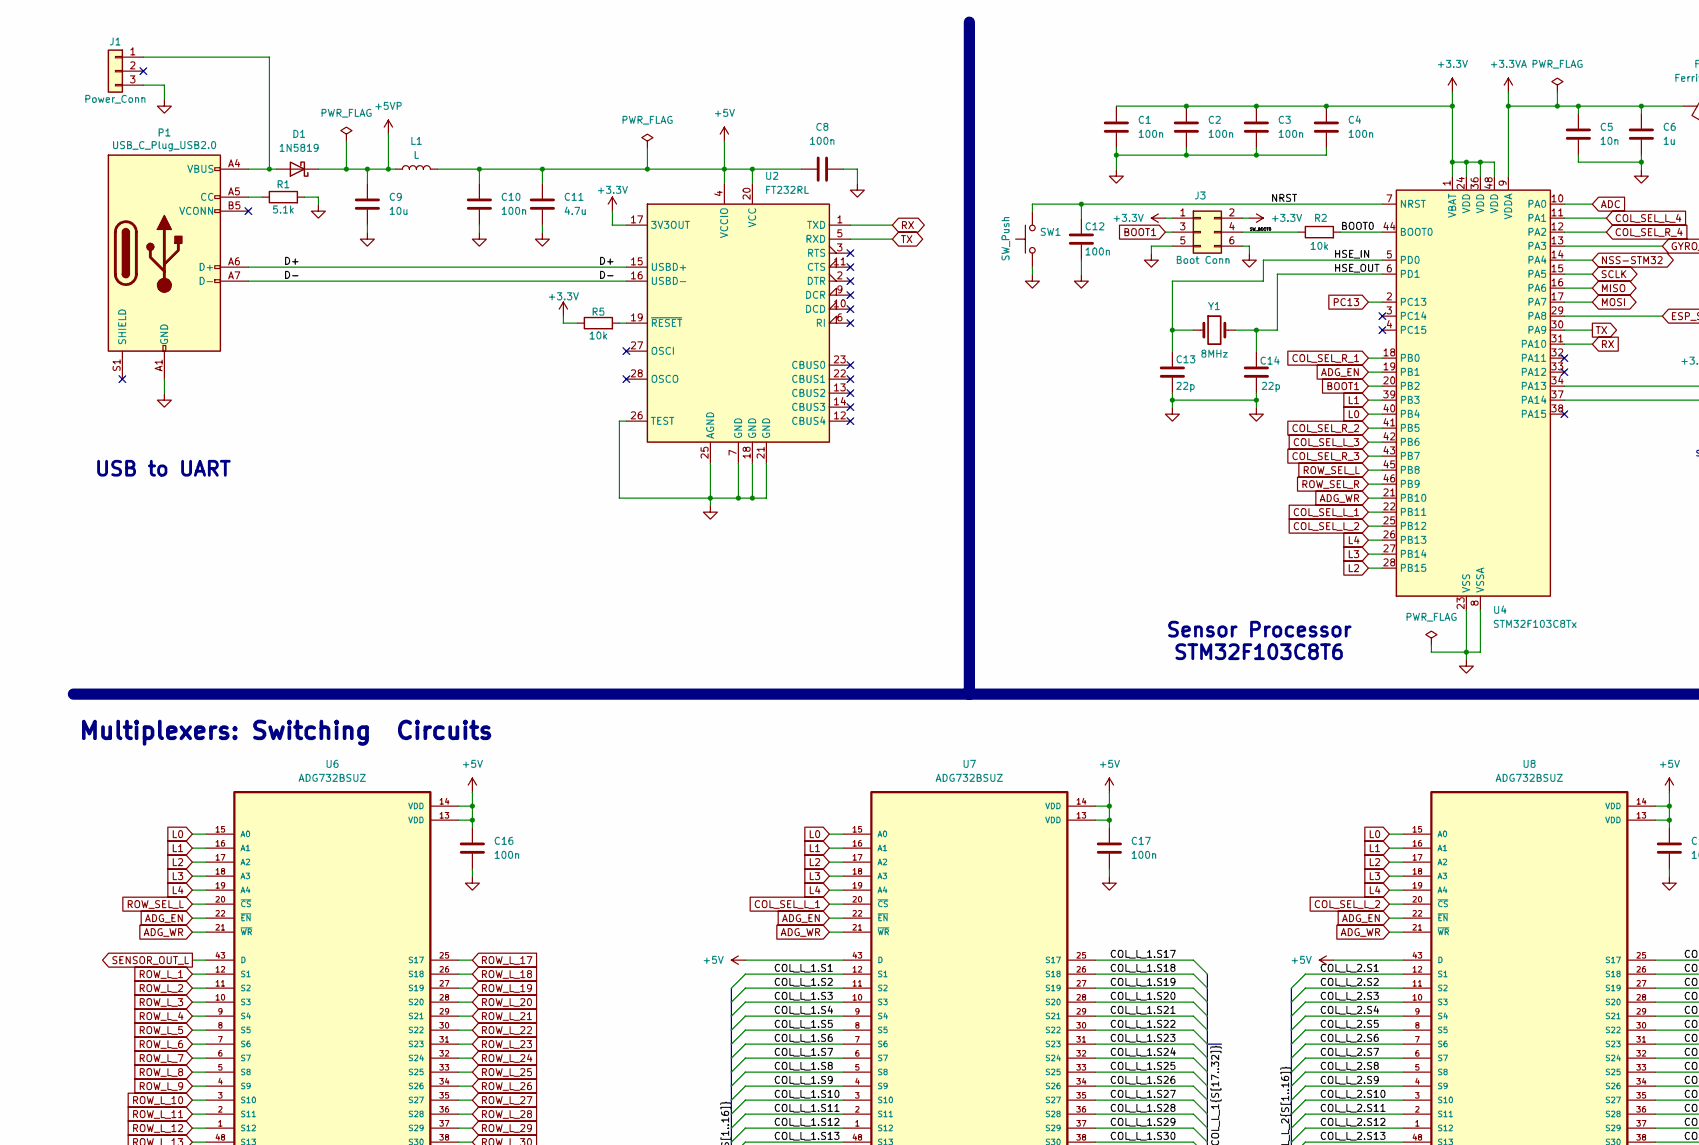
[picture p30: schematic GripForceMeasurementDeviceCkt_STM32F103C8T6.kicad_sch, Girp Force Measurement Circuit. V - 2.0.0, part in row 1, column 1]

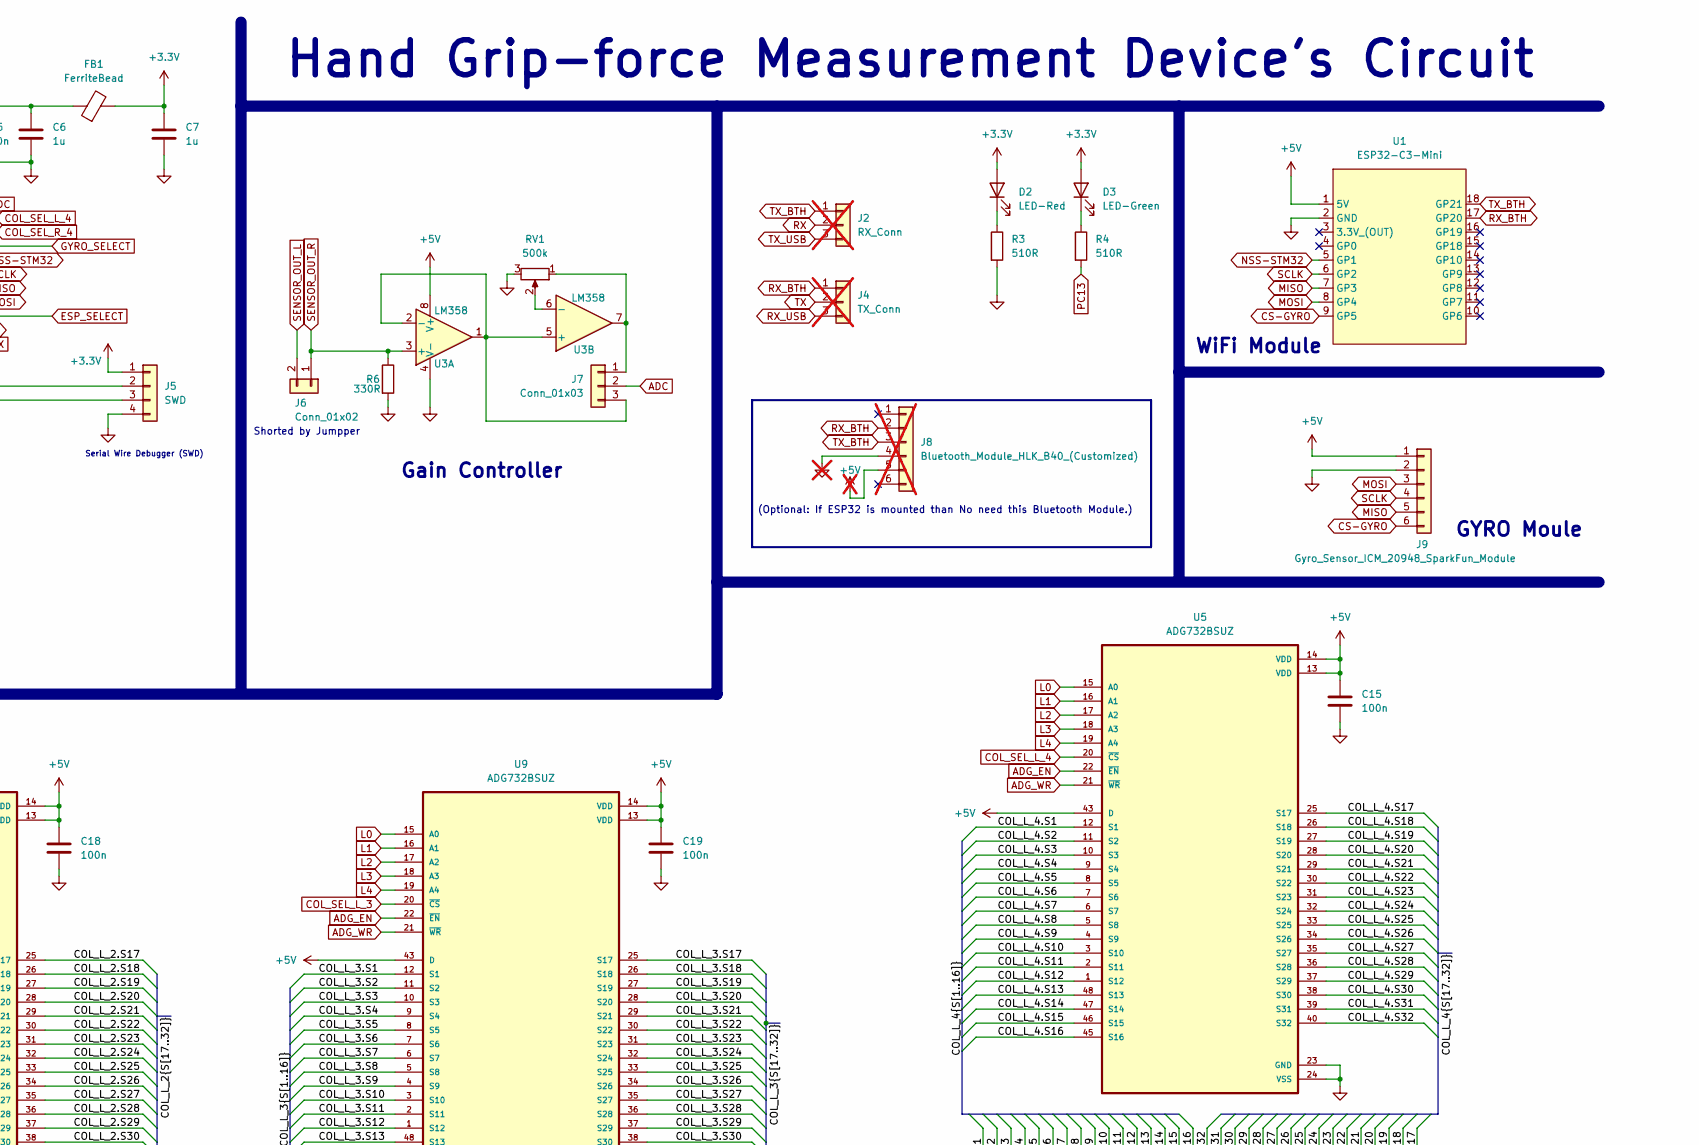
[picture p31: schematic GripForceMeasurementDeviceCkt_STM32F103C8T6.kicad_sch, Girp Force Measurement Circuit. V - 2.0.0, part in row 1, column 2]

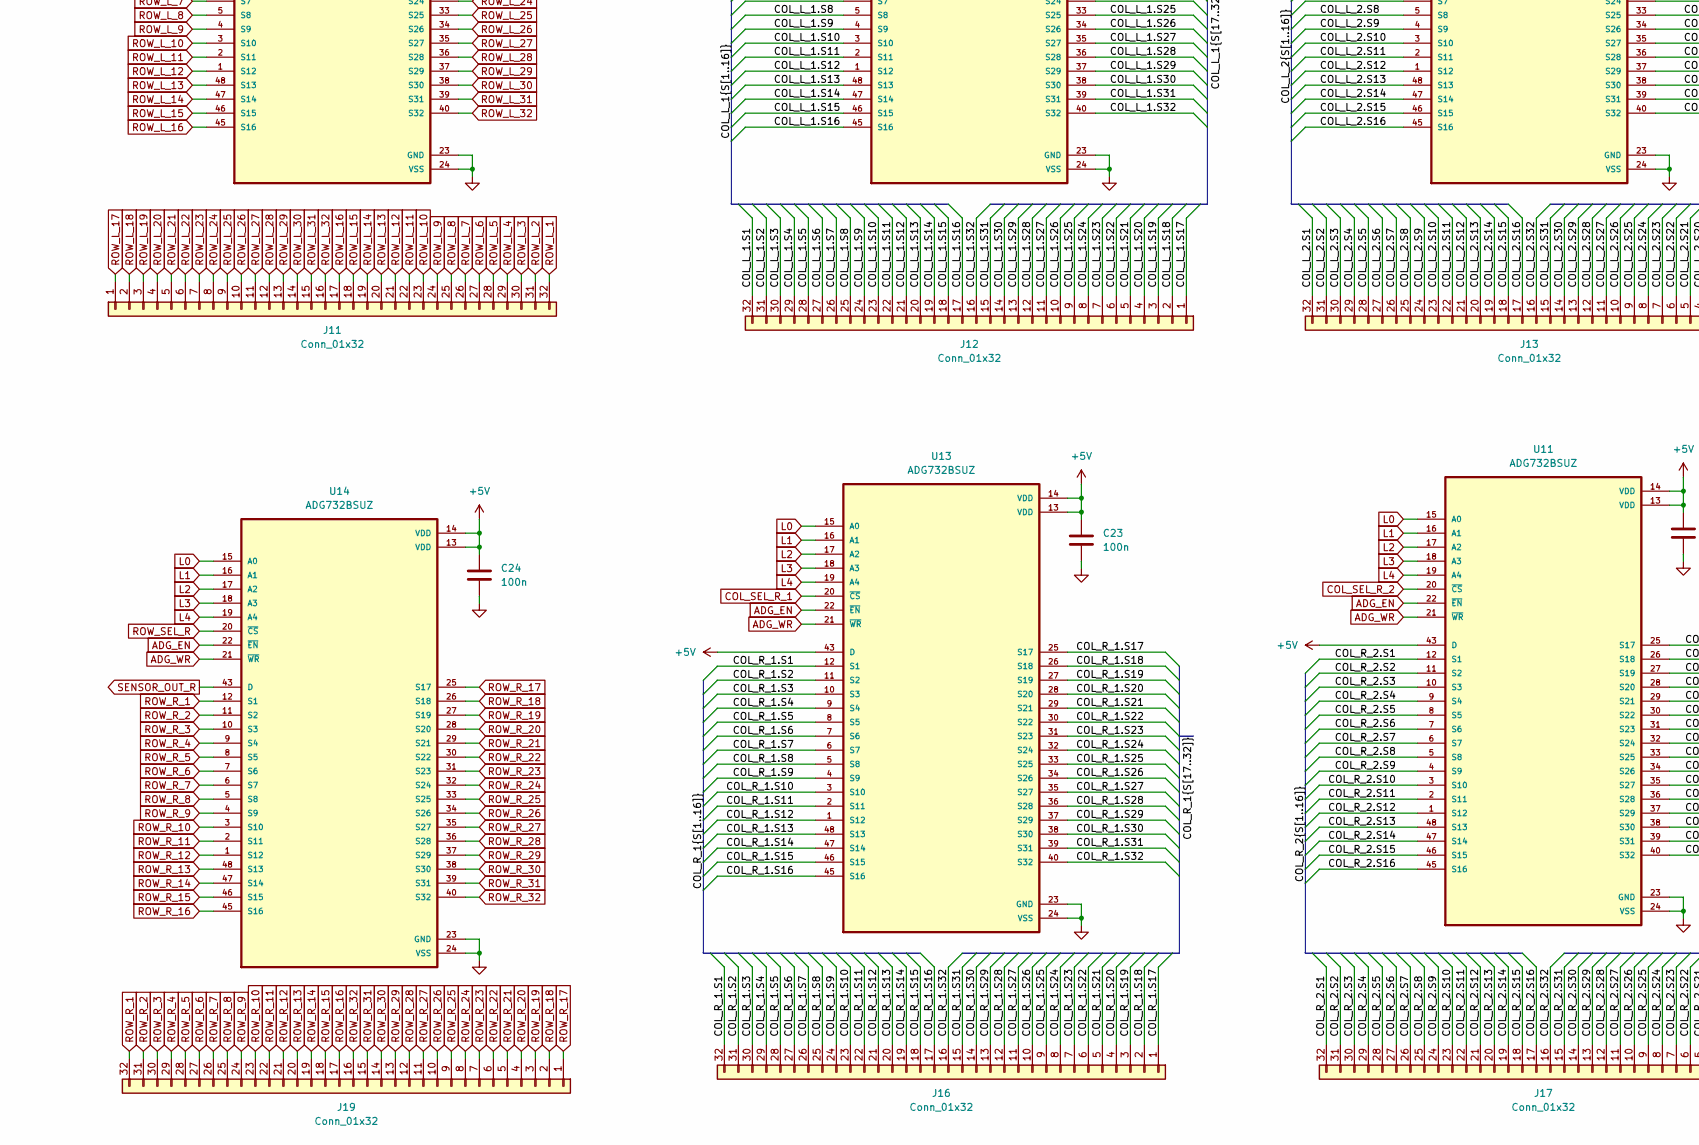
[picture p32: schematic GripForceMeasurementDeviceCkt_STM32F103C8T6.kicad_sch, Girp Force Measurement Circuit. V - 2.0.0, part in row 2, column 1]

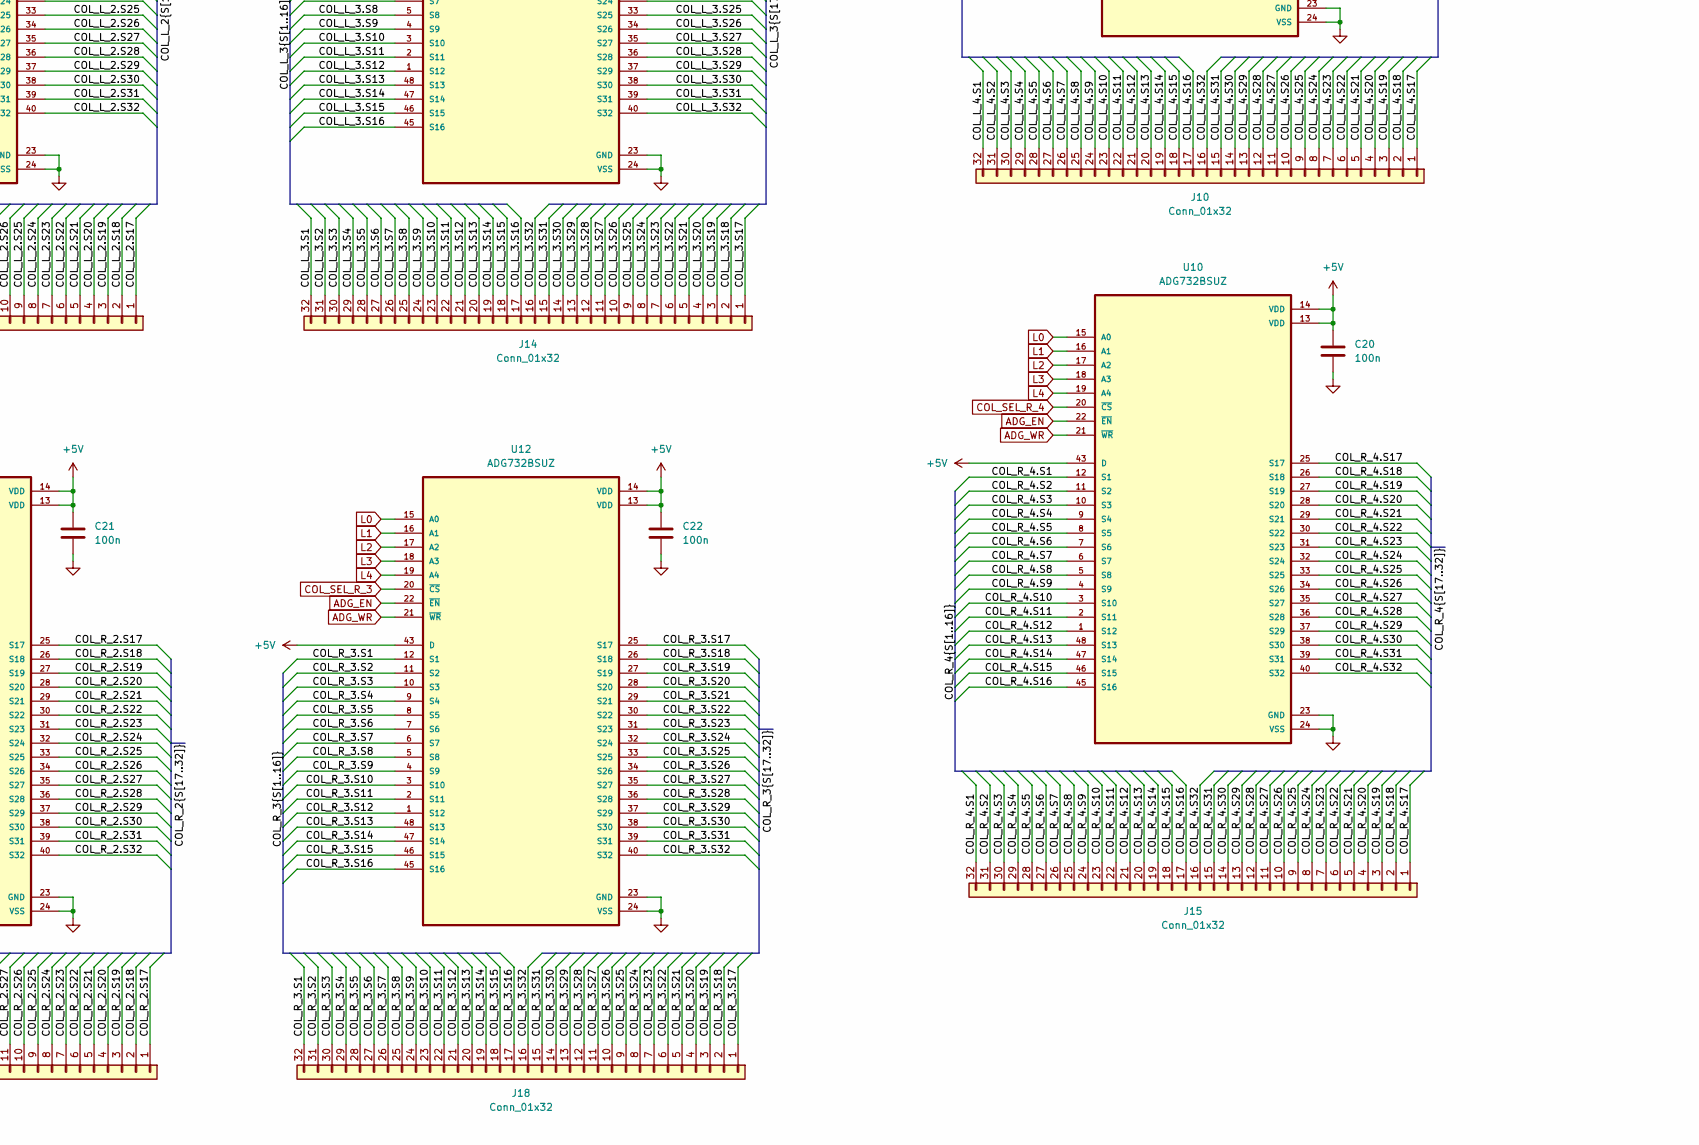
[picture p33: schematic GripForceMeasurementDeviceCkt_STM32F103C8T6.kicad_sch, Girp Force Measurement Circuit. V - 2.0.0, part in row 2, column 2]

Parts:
C1, C2, C3, C4, C8, C10, C12, C15, C16, C17, C18, C19, C20, C21, C22, C23, C24: 100n; C_0603_1608Metric; JLCPCB Part # C14663
C5: 10n; C_0603_1608Metric; JLCPCB Part # C57112
C6, C7: 1u; C_0603_1608Metric; JLCPCB Part # C15849
C9: 10u; C_1206_3216Metric; JLCPCB Part # C13585
C11: 4.7u; C_1206_3216Metric; JLCPCB Part # C29823
C13, C14: 22p; C_0603_1608Metric; JLCPCB Part # C105620
D1: 1N5819; D_SOD-323_HandSoldering; JLCPCB Part # C6067464
D2: LED-Red; LED_0603_1608Metric; JLCPCB Part # C5355420, C5355434
D3: LED-Green; LED_0603_1608Metric; JLCPCB Part # C19171301
FB1: FerriteBead; L_0805_2012Metric; JLCPCB Part # C85840
J1: Power_Conn; PinHeader_1x03_P2.54mm_Vertical; JLCPCB Part # C706875
J2: RX_Conn; PinHeader_1x03_P2.54mm_Vertical; not fitted
J3: Boot Conn; PinHeader_2x03_P2.54mm_Vertical; JLCPCB Part # C7501274
J4: TX_Conn; PinHeader_1x03_P2.54mm_Vertical; not fitted
J5: SWD; PinHeader_1x04_P2.54mm_Vertical; JLCPCB Part # C2691448
J6: Conn_01x02; PinHeader_1x02_P2.54mm_Vertical; JLCPCB Part # C706874
J7: Conn_01x03; PinHeader_1x03_P2.54mm_Vertical; JLCPCB Part # C706875
J8: Bluetooth_Module_HLK_B40_(Customized); PinSocket_1x06_P2.54mm_Vertical; not fitted
J9: Gyro_Sensor_ICM_20948_SparkFun_Module; PinSocket_1x06_P2.54mm_Vertical; JLCPCB Part # C6332199
J10, J11, J12, J13, J14, J15, J16, J17, J18, J19: Conn_01x32; Hirose_FH12-32S-0.5SH_1x32-1MP_P0.50mm_Horizontal; JLCPCB Part # C262672
L1: L; L_0603_1608Metric; JLCPCB Part # C139179
P1: USB_C_Plug_USB2.0; USB_C_Receptacle_Amphenol_12401610E4-2A; JLCPCB Part # C5119948
R1: 5.1k; R_0603_1608Metric; JLCPCB Part # C23186
R2, R5: 10k; R_0603_1608Metric; JLCPCB Part # C25804
R3, R4: 510R; R_0603_1608Metric; JLCPCB Part # C2073794
R6: 330R; R_Axial_DIN0207_L6.3mm_D2.5mm_P10.16mm_Horizontal; JLCPCB Part # C173152
RV1: 500k; Potentiometer_Bourns_3296W_Vertical; JLCPCB Part # C118921
SW1: SW_Push; SW_Tactile_SPST_NO_Straight_CK_PTS636Sx25SMTRLFS; JLCPCB Part # C318938
U1: ESP32-C3-Mini; ESP32-C3-Mini-through-hole
U2: FT232RL; SSOP-28_5.3x10.2mm_P0.65mm; JLCPCB Part # C8690
U3: LM358; SO-8_3.9x4.9mm_P1.27mm; JLCPCB Part # C5296727
U4: STM32F103C8Tx; LQFP-48_7x7mm_P0.5mm; JLCPCB Part # C8734
U5, U6, U7, U8, U9, U10, U11, U12, U13, U14: ADG732BSUZ; TQFP-48_7x7mm_P0.5mm; JLCPCB Part # C114845
Y1: 8MHz; Crystal_HC49-4H_Vertical; JLCPCB Part # C21263

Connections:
+3.3V: C1.1, C2.1, C3.1, C4.1, C7.1, D2.2 (A), D3.2 (A), FB1.2, J3.1, J3.2, J5.1, R5.1, U2.17 (3V3OUT), U4.1 (VBAT), U4.24 (VDD), U4.36 (VDD), U4.48 (VDD)
+3.3VA: C5.1, C6.1, FB1.1, U4.9 (VDDA)
+5V: C8.2, C10.1, C11.1, C15.1, C16.1, C17.1, C18.1, C19.1, C20.1, C21.1, C22.1, C23.1, C24.1, J8.5, J9.1, L1.2, U1.1 (5V), U2.4 (VCCIO), U2.20 (VCC), U3.8 (V+), U5.13 (VDD), U5.14 (VDD), U5.43 (D), U6.13 (VDD), U6.14 (VDD), U7.13 (VDD), U7.14 (VDD), U7.43 (D), U8.13 (VDD), U8.14 (VDD), U8.43 (D), U9.13 (VDD), U9.14 (VDD), U9.43 (D), U10.13 (VDD), U10.14 (VDD), U10.43 (D), U11.13 (VDD), U11.14 (VDD), U11.43 (D), U12.13 (VDD), U12.14 (VDD), U12.43 (D), U13.13 (VDD), U13.14 (VDD), U13.43 (D), U14.13 (VDD), U14.14 (VDD)
+5VP: C9.1, D1.1 (K), L1.1
/BOOT0: R2.2, U4.44 (BOOT0)
/COL_L_1.S1: J12.32, U7.12 (S1)
/COL_L_1.S2: J12.31, U7.11 (S2)
/COL_L_1.S3: J12.30, U7.10 (S3)
/COL_L_1.S4: J12.29, U7.9 (S4)
/COL_L_1.S5: J12.28, U7.8 (S5)
/COL_L_1.S6: J12.27, U7.7 (S6)
/COL_L_1.S7: J12.26, U7.6 (S7)
/COL_L_1.S8: J12.25, U7.5 (S8)
/COL_L_1.S9: J12.24, U7.4 (S9)
/COL_L_1.S10: J12.23, U7.3 (S10)
/COL_L_1.S11: J12.22, U7.2 (S11)
/COL_L_1.S12: J12.21, U7.1 (S12)
/COL_L_1.S13: J12.20, U7.48 (S13)
/COL_L_1.S14: J12.19, U7.47 (S14)
/COL_L_1.S15: J12.18, U7.46 (S15)
/COL_L_1.S16: J12.17, U7.45 (S16)
/COL_L_1.S17: J12.1, U7.25 (S17)
/COL_L_1.S18: J12.2, U7.26 (S18)
/COL_L_1.S19: J12.3, U7.27 (S19)
/COL_L_1.S20: J12.4, U7.28 (S20)
/COL_L_1.S21: J12.5, U7.29 (S21)
/COL_L_1.S22: J12.6, U7.30 (S22)
/COL_L_1.S23: J12.7, U7.31 (S23)
/COL_L_1.S24: J12.8, U7.32 (S24)
/COL_L_1.S25: J12.9, U7.33 (S25)
/COL_L_1.S26: J12.10, U7.34 (S26)
/COL_L_1.S27: J12.11, U7.35 (S27)
/COL_L_1.S28: J12.12, U7.36 (S28)
/COL_L_1.S29: J12.13, U7.37 (S29)
/COL_L_1.S30: J12.14, U7.38 (S30)
/COL_L_1.S31: J12.15, U7.39 (S31)
/COL_L_1.S32: J12.16, U7.40 (S32)
/COL_L_2.S1: J13.32, U8.12 (S1)
/COL_L_2.S2: J13.31, U8.11 (S2)
/COL_L_2.S3: J13.30, U8.10 (S3)
/COL_L_2.S4: J13.29, U8.9 (S4)
/COL_L_2.S5: J13.28, U8.8 (S5)
/COL_L_2.S6: J13.27, U8.7 (S6)
/COL_L_2.S7: J13.26, U8.6 (S7)
/COL_L_2.S8: J13.25, U8.5 (S8)
/COL_L_2.S9: J13.24, U8.4 (S9)
/COL_L_2.S10: J13.23, U8.3 (S10)
/COL_L_2.S11: J13.22, U8.2 (S11)
/COL_L_2.S12: J13.21, U8.1 (S12)
/COL_L_2.S13: J13.20, U8.48 (S13)
/COL_L_2.S14: J13.19, U8.47 (S14)
/COL_L_2.S15: J13.18, U8.46 (S15)
/COL_L_2.S16: J13.17, U8.45 (S16)
/COL_L_2.S17: J13.1, U8.25 (S17)
/COL_L_2.S18: J13.2, U8.26 (S18)
/COL_L_2.S19: J13.3, U8.27 (S19)
/COL_L_2.S20: J13.4, U8.28 (S20)
/COL_L_2.S21: J13.5, U8.29 (S21)
/COL_L_2.S22: J13.6, U8.30 (S22)
/COL_L_2.S23: J13.7, U8.31 (S23)
/COL_L_2.S24: J13.8, U8.32 (S24)
/COL_L_2.S25: J13.9, U8.33 (S25)
/COL_L_2.S26: J13.10, U8.34 (S26)
/COL_L_2.S27: J13.11, U8.35 (S27)
/COL_L_2.S28: J13.12, U8.36 (S28)
/COL_L_2.S29: J13.13, U8.37 (S29)
/COL_L_2.S30: J13.14, U8.38 (S30)
/COL_L_2.S31: J13.15, U8.39 (S31)
/COL_L_2.S32: J13.16, U8.40 (S32)
/COL_L_3.S1: J14.32, U9.12 (S1)
/COL_L_3.S2: J14.31, U9.11 (S2)
/COL_L_3.S3: J14.30, U9.10 (S3)
/COL_L_3.S4: J14.29, U9.9 (S4)
/COL_L_3.S5: J14.28, U9.8 (S5)
/COL_L_3.S6: J14.27, U9.7 (S6)
/COL_L_3.S7: J14.26, U9.6 (S7)
/COL_L_3.S8: J14.25, U9.5 (S8)
/COL_L_3.S9: J14.24, U9.4 (S9)
/COL_L_3.S10: J14.23, U9.3 (S10)
/COL_L_3.S11: J14.22, U9.2 (S11)
/COL_L_3.S12: J14.21, U9.1 (S12)
/COL_L_3.S13: J14.20, U9.48 (S13)
/COL_L_3.S14: J14.19, U9.47 (S14)
/COL_L_3.S15: J14.18, U9.46 (S15)
/COL_L_3.S16: J14.17, U9.45 (S16)
/COL_L_3.S17: J14.1, U9.25 (S17)
/COL_L_3.S18: J14.2, U9.26 (S18)
/COL_L_3.S19: J14.3, U9.27 (S19)
/COL_L_3.S20: J14.4, U9.28 (S20)
/COL_L_3.S21: J14.5, U9.29 (S21)
/COL_L_3.S22: J14.6, U9.30 (S22)
/COL_L_3.S23: J14.7, U9.31 (S23)
/COL_L_3.S24: J14.8, U9.32 (S24)
/COL_L_3.S25: J14.9, U9.33 (S25)
/COL_L_3.S26: J14.10, U9.34 (S26)
/COL_L_3.S27: J14.11, U9.35 (S27)
/COL_L_3.S28: J14.12, U9.36 (S28)
/COL_L_3.S29: J14.13, U9.37 (S29)
/COL_L_3.S30: J14.14, U9.38 (S30)
/COL_L_3.S31: J14.15, U9.39 (S31)
/COL_L_3.S32: J14.16, U9.40 (S32)
/COL_L_4.S1: J10.32, U5.12 (S1)
/COL_L_4.S2: J10.31, U5.11 (S2)
/COL_L_4.S3: J10.30, U5.10 (S3)
/COL_L_4.S4: J10.29, U5.9 (S4)
/COL_L_4.S5: J10.28, U5.8 (S5)
/COL_L_4.S6: J10.27, U5.7 (S6)
/COL_L_4.S7: J10.26, U5.6 (S7)
/COL_L_4.S8: J10.25, U5.5 (S8)
/COL_L_4.S9: J10.24, U5.4 (S9)
/COL_L_4.S10: J10.23, U5.3 (S10)
/COL_L_4.S11: J10.22, U5.2 (S11)
/COL_L_4.S12: J10.21, U5.1 (S12)
/COL_L_4.S13: J10.20, U5.48 (S13)
/COL_L_4.S14: J10.19, U5.47 (S14)
/COL_L_4.S15: J10.18, U5.46 (S15)
/COL_L_4.S16: J10.17, U5.45 (S16)
/COL_L_4.S17: J10.1, U5.25 (S17)
/COL_L_4.S18: J10.2, U5.26 (S18)
/COL_L_4.S19: J10.3, U5.27 (S19)
/COL_L_4.S20: J10.4, U5.28 (S20)
/COL_L_4.S21: J10.5, U5.29 (S21)
/COL_L_4.S22: J10.6, U5.30 (S22)
/COL_L_4.S23: J10.7, U5.31 (S23)
/COL_L_4.S24: J10.8, U5.32 (S24)
/COL_L_4.S25: J10.9, U5.33 (S25)
/COL_L_4.S26: J10.10, U5.34 (S26)
/COL_L_4.S27: J10.11, U5.35 (S27)
/COL_L_4.S28: J10.12, U5.36 (S28)
/COL_L_4.S29: J10.13, U5.37 (S29)
/COL_L_4.S30: J10.14, U5.38 (S30)
/COL_L_4.S31: J10.15, U5.39 (S31)
/COL_L_4.S32: J10.16, U5.40 (S32)
/COL_R_1.S1: J16.32, U13.12 (S1)
/COL_R_1.S2: J16.31, U13.11 (S2)
/COL_R_1.S3: J16.30, U13.10 (S3)
/COL_R_1.S4: J16.29, U13.9 (S4)
/COL_R_1.S5: J16.28, U13.8 (S5)
/COL_R_1.S6: J16.27, U13.7 (S6)
/COL_R_1.S7: J16.26, U13.6 (S7)
/COL_R_1.S8: J16.25, U13.5 (S8)
/COL_R_1.S9: J16.24, U13.4 (S9)
/COL_R_1.S10: J16.23, U13.3 (S10)
/COL_R_1.S11: J16.22, U13.2 (S11)
/COL_R_1.S12: J16.21, U13.1 (S12)
/COL_R_1.S13: J16.20, U13.48 (S13)
/COL_R_1.S14: J16.19, U13.47 (S14)
/COL_R_1.S15: J16.18, U13.46 (S15)
/COL_R_1.S16: J16.17, U13.45 (S16)
/COL_R_1.S17: J16.1, U13.25 (S17)
/COL_R_1.S18: J16.2, U13.26 (S18)
/COL_R_1.S19: J16.3, U13.27 (S19)
/COL_R_1.S20: J16.4, U13.28 (S20)
/COL_R_1.S21: J16.5, U13.29 (S21)
/COL_R_1.S22: J16.6, U13.30 (S22)
/COL_R_1.S23: J16.7, U13.31 (S23)
/COL_R_1.S24: J16.8, U13.32 (S24)
/COL_R_1.S25: J16.9, U13.33 (S25)
/COL_R_1.S26: J16.10, U13.34 (S26)
/COL_R_1.S27: J16.11, U13.35 (S27)
/COL_R_1.S28: J16.12, U13.36 (S28)
/COL_R_1.S29: J16.13, U13.37 (S29)
/COL_R_1.S30: J16.14, U13.38 (S30)
/COL_R_1.S31: J16.15, U13.39 (S31)
/COL_R_1.S32: J16.16, U13.40 (S32)
/COL_R_2.S1: J17.32, U11.12 (S1)
/COL_R_2.S2: J17.31, U11.11 (S2)
/COL_R_2.S3: J17.30, U11.10 (S3)
/COL_R_2.S4: J17.29, U11.9 (S4)
/COL_R_2.S5: J17.28, U11.8 (S5)
/COL_R_2.S6: J17.27, U11.7 (S6)
/COL_R_2.S7: J17.26, U11.6 (S7)
/COL_R_2.S8: J17.25, U11.5 (S8)
/COL_R_2.S9: J17.24, U11.4 (S9)
/COL_R_2.S10: J17.23, U11.3 (S10)
/COL_R_2.S11: J17.22, U11.2 (S11)
/COL_R_2.S12: J17.21, U11.1 (S12)
/COL_R_2.S13: J17.20, U11.48 (S13)
/COL_R_2.S14: J17.19, U11.47 (S14)
/COL_R_2.S15: J17.18, U11.46 (S15)
/COL_R_2.S16: J17.17, U11.45 (S16)
/COL_R_2.S17: J17.1, U11.25 (S17)
/COL_R_2.S18: J17.2, U11.26 (S18)
/COL_R_2.S19: J17.3, U11.27 (S19)
/COL_R_2.S20: J17.4, U11.28 (S20)
/COL_R_2.S21: J17.5, U11.29 (S21)
/COL_R_2.S22: J17.6, U11.30 (S22)
/COL_R_2.S23: J17.7, U11.31 (S23)
/COL_R_2.S24: J17.8, U11.32 (S24)
/COL_R_2.S25: J17.9, U11.33 (S25)
/COL_R_2.S26: J17.10, U11.34 (S26)
/COL_R_2.S27: J17.11, U11.35 (S27)
/COL_R_2.S28: J17.12, U11.36 (S28)
/COL_R_2.S29: J17.13, U11.37 (S29)
/COL_R_2.S30: J17.14, U11.38 (S30)
/COL_R_2.S31: J17.15, U11.39 (S31)
/COL_R_2.S32: J17.16, U11.40 (S32)
/COL_R_3.S1: J18.32, U12.12 (S1)
/COL_R_3.S2: J18.31, U12.11 (S2)
/COL_R_3.S3: J18.30, U12.10 (S3)
/COL_R_3.S4: J18.29, U12.9 (S4)
/COL_R_3.S5: J18.28, U12.8 (S5)
/COL_R_3.S6: J18.27, U12.7 (S6)
/COL_R_3.S7: J18.26, U12.6 (S7)
/COL_R_3.S8: J18.25, U12.5 (S8)
/COL_R_3.S9: J18.24, U12.4 (S9)
/COL_R_3.S10: J18.23, U12.3 (S10)
/COL_R_3.S11: J18.22, U12.2 (S11)
/COL_R_3.S12: J18.21, U12.1 (S12)
/COL_R_3.S13: J18.20, U12.48 (S13)
/COL_R_3.S14: J18.19, U12.47 (S14)
/COL_R_3.S15: J18.18, U12.46 (S15)
/COL_R_3.S16: J18.17, U12.45 (S16)
/COL_R_3.S17: J18.1, U12.25 (S17)
/COL_R_3.S18: J18.2, U12.26 (S18)
/COL_R_3.S19: J18.3, U12.27 (S19)
/COL_R_3.S20: J18.4, U12.28 (S20)
/COL_R_3.S21: J18.5, U12.29 (S21)
/COL_R_3.S22: J18.6, U12.30 (S22)
/COL_R_3.S23: J18.7, U12.31 (S23)
/COL_R_3.S24: J18.8, U12.32 (S24)
/COL_R_3.S25: J18.9, U12.33 (S25)
/COL_R_3.S26: J18.10, U12.34 (S26)
/COL_R_3.S27: J18.11, U12.35 (S27)
/COL_R_3.S28: J18.12, U12.36 (S28)
/COL_R_3.S29: J18.13, U12.37 (S29)
/COL_R_3.S30: J18.14, U12.38 (S30)
/COL_R_3.S31: J18.15, U12.39 (S31)
/COL_R_3.S32: J18.16, U12.40 (S32)
/COL_R_4.S1: J15.32, U10.12 (S1)
/COL_R_4.S2: J15.31, U10.11 (S2)
/COL_R_4.S3: J15.30, U10.10 (S3)
/COL_R_4.S4: J15.29, U10.9 (S4)
/COL_R_4.S5: J15.28, U10.8 (S5)
/COL_R_4.S6: J15.27, U10.7 (S6)
/COL_R_4.S7: J15.26, U10.6 (S7)
/COL_R_4.S8: J15.25, U10.5 (S8)
/COL_R_4.S9: J15.24, U10.4 (S9)
/COL_R_4.S10: J15.23, U10.3 (S10)
/COL_R_4.S11: J15.22, U10.2 (S11)
/COL_R_4.S12: J15.21, U10.1 (S12)
/COL_R_4.S13: J15.20, U10.48 (S13)
/COL_R_4.S14: J15.19, U10.47 (S14)
/COL_R_4.S15: J15.18, U10.46 (S15)
/COL_R_4.S16: J15.17, U10.45 (S16)
/COL_R_4.S17: J15.1, U10.25 (S17)
/COL_R_4.S18: J15.2, U10.26 (S18)
/COL_R_4.S19: J15.3, U10.27 (S19)
/COL_R_4.S20: J15.4, U10.28 (S20)
/COL_R_4.S21: J15.5, U10.29 (S21)
/COL_R_4.S22: J15.6, U10.30 (S22)
/COL_R_4.S23: J15.7, U10.31 (S23)
/COL_R_4.S24: J15.8, U10.32 (S24)
/COL_R_4.S25: J15.9, U10.33 (S25)
/COL_R_4.S26: J15.10, U10.34 (S26)
/COL_R_4.S27: J15.11, U10.35 (S27)
/COL_R_4.S28: J15.12, U10.36 (S28)
/COL_R_4.S29: J15.13, U10.37 (S29)
/COL_R_4.S30: J15.14, U10.38 (S30)
/COL_R_4.S31: J15.15, U10.39 (S31)
/COL_R_4.S32: J15.16, U10.40 (S32)
/D+: P1.A6 (D+), U2.15 (USBD+)
/D-: P1.A7 (D-), U2.16 (USBD-)
/HSE_IN: C13.1, U4.5 (PD0), Y1.1
/HSE_OUT: C14.1, U4.6 (PD1), Y1.2
/NRST: C12.1, SW1.2, U4.7 (NRST)
/SW_BOOT0: J3.4, R2.1
ADC: J7.2, U4.10 (PA0)
ADG_EN: U4.19 (PB1), U5.22 (~EN), U6.22 (~EN), U7.22 (~EN), U8.22 (~EN), U9.22 (~EN), U10.22 (~EN), U11.22 (~EN), U12.22 (~EN), U13.22 (~EN), U14.22 (~EN)
ADG_WR: U4.21 (PB10), U5.21 (~WR), U6.21 (~WR), U7.21 (~WR), U8.21 (~WR), U9.21 (~WR), U10.21 (~WR), U11.21 (~WR), U12.21 (~WR), U13.21 (~WR), U14.21 (~WR)
BOOT1: J3.3, U4.20 (PB2)
COL_SEL_L_1: U4.22 (PB11), U7.20 (~CS)
COL_SEL_L_2: U4.25 (PB12), U8.20 (~CS)
COL_SEL_L_3: U4.42 (PB6), U9.20 (~CS)
COL_SEL_L_4: U4.11 (PA1), U5.20 (~CS)
COL_SEL_R_1: U4.18 (PB0), U13.20 (~CS)
COL_SEL_R_2: U4.41 (PB5), U11.20 (~CS)
COL_SEL_R_3: U4.43 (PB7), U12.20 (~CS)
COL_SEL_R_4: U4.12 (PA2), U10.20 (~CS)
CS-GYRO: J9.6, U1.9 (GP5)
ESP_SELECT: U4.29 (PA8)
GND: C1.2, C2.2, C3.2, C4.2, C5.2, C6.2, C7.2, C8.1, C9.2, C10.2, C11.2, C12.2, C13.2, C14.2, C15.2, C16.2, C17.2, C18.2, C19.2, C20.2, C21.2, C22.2, C23.2, C24.2, J1.3, J3.5, J3.6, J5.4, J8.4, J9.2, P1.A1 (GND), P1.A12 (GND), P1.B1 (GND), P1.B12 (GND), R1.2, R3.2, R6.2, RV1.3, SW1.1, U1.2 (GND), U2.7 (GND), U2.18 (GND), U2.21 (GND), U2.25 (AGND), U2.26 (TEST), U3.4 (V-), U4.8 (VSSA), U4.23 (VSS), U4.35 (VSS), U4.47 (VSS), U5.23 (GND), U5.24 (VSS), U6.23 (GND), U6.24 (VSS), U7.23 (GND), U7.24 (VSS), U8.23 (GND), U8.24 (VSS), U9.23 (GND), U9.24 (VSS), U10.23 (GND), U10.24 (VSS), U11.23 (GND), U11.24 (VSS), U12.23 (GND), U12.24 (VSS), U13.23 (GND), U13.24 (VSS), U14.23 (GND), U14.24 (VSS)
GYRO_SELECT: U4.13 (PA3)
L0: U4.40 (PB4), U5.15 (A0), U6.15 (A0), U7.15 (A0), U8.15 (A0), U9.15 (A0), U10.15 (A0), U11.15 (A0), U12.15 (A0), U13.15 (A0), U14.15 (A0)
L1: U4.39 (PB3), U5.16 (A1), U6.16 (A1), U7.16 (A1), U8.16 (A1), U9.16 (A1), U10.16 (A1), U11.16 (A1), U12.16 (A1), U13.16 (A1), U14.16 (A1)
L2: U4.28 (PB15), U5.17 (A2), U6.17 (A2), U7.17 (A2), U8.17 (A2), U9.17 (A2), U10.17 (A2), U11.17 (A2), U12.17 (A2), U13.17 (A2), U14.17 (A2)
L3: U4.27 (PB14), U5.18 (A3), U6.18 (A3), U7.18 (A3), U8.18 (A3), U9.18 (A3), U10.18 (A3), U11.18 (A3), U12.18 (A3), U13.18 (A3), U14.18 (A3)
L4: U4.26 (PB13), U5.19 (A4), U6.19 (A4), U7.19 (A4), U8.19 (A4), U9.19 (A4), U10.19 (A4), U11.19 (A4), U12.19 (A4), U13.19 (A4), U14.19 (A4)
MISO: J9.5, U1.7 (GP3), U4.16 (PA6)
MOSI: J9.3, U1.8 (GP4), U4.17 (PA7)
NSS-STM32: U1.5 (GP1), U4.14 (PA4)
unnamed: D1.2 (A), J1.1, P1.A4 (VBUS), P1.A9 (VBUS), P1.B4 (VBUS), P1.B9 (VBUS)
unnamed: D2.1 (K), R3.1
unnamed: D3.1 (K), R4.1
unnamed: J5.2, U4.34 (PA13)
unnamed: J5.3, U4.37 (PA14)
unnamed: J7.1, RV1.1, U3.7
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

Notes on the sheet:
Hand Grip-force Measurement Device's Circuit
Serial Wire Debugger (SWD)
Gain Controller
Sensor Processor STM32F103C8T6
Shorted by Jumpper
GYRO Moule
Multiplexers: Switching Circuits
(Optional: If ESP32 is mounted than No need this Bluetooth Module.)
USB to UART
WiFi Module

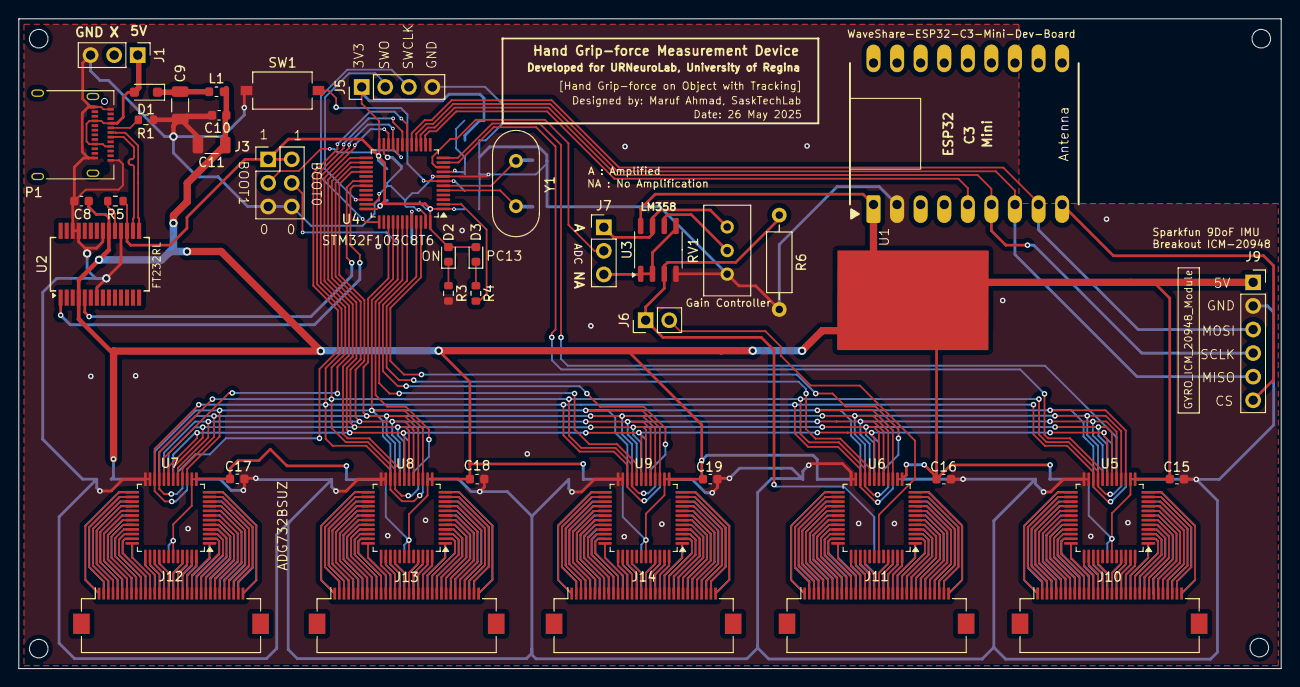
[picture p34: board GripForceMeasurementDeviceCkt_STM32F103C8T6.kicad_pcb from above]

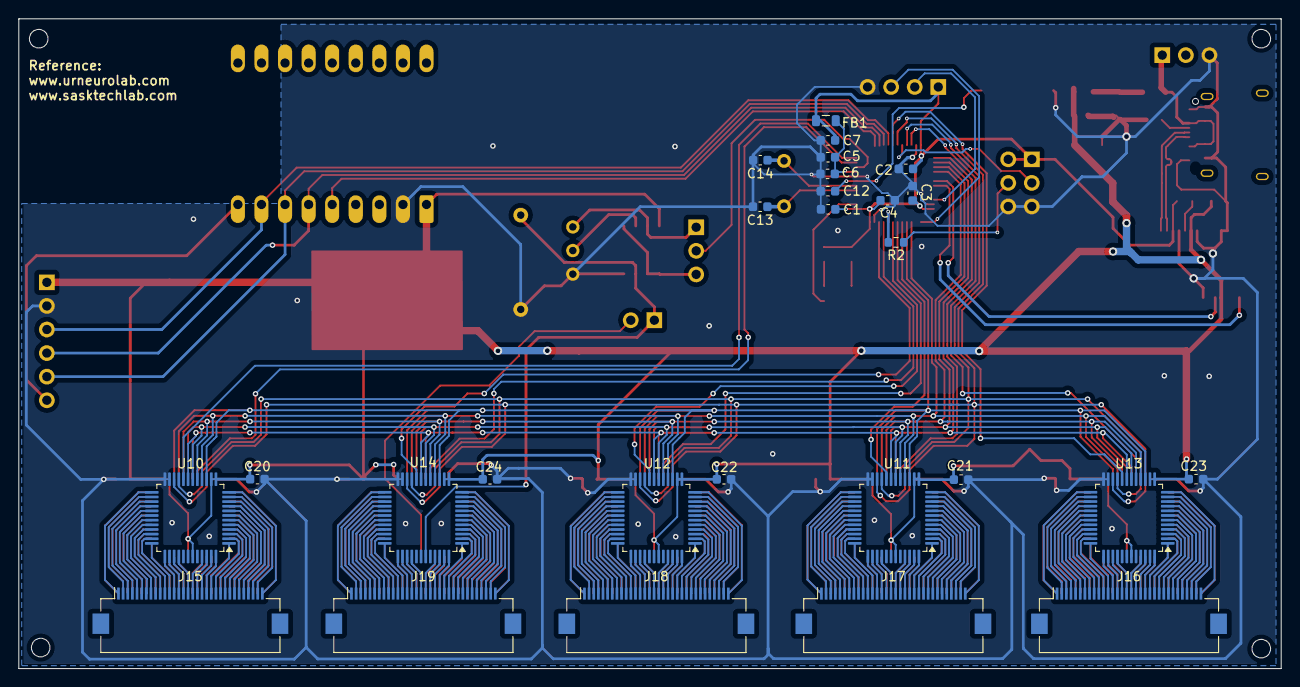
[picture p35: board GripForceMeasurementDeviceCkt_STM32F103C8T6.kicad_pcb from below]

Board: 2 copper layers, 136.0 x 70.0 mm, 69 parts (27 on the bottom side), 371 nets.

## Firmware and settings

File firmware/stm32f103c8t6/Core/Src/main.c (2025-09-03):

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
/* Includes ------------------------------------------------------------------*/
#include "main.h"

/* USER CODE BEGIN Includes */
#include <stdio.h>
#include <string.h>
/* USER CODE END Includes */

/* USER CODE BEGIN PD */

//#define A0_PIN GPIO_PIN_5
//#define A1_PIN GPIO_PIN_6
//#define A2_PIN GPIO_PIN_7
//#define A3_PIN GPIO_PIN_8
//#define A4_PIN GPIO_PIN_9
//#define ROW_CS_PIN GPIO_PIN_12
//#define COL1_CS_PIN GPIO_PIN_13
//#define COL2_CS_PIN GPIO_PIN_14

#define WR_PIN GPIO_PIN_10
#define EN_PIN GPIO_PIN_1
#define GPIO_PORT GPIOB

#define DELAY_MicroSec 10

#define GPIO_PORT_A GPIOA
#define GPIO_PORT_B GPIOB

#define A0_PIN GPIO_PIN_4
#define A1_PIN GPIO_PIN_3
#define A2_PIN GPIO_PIN_15
#define A3_PIN GPIO_PIN_14
#define A4_PIN GPIO_PIN_13

#define CON_SEL_R_1 GPIO_PIN_0
#define CON_SEL_R_2 GPIO_PIN_5
#define CON_SEL_R_3 GPIO_PIN_7
#define CON_SEL_R_4 GPIO_PIN_2		// PORTA

#define CON_SEL_L_1 GPIO_PIN_11
#define CON_SEL_L_2 GPIO_PIN_12
#define CON_SEL_L_3 GPIO_PIN_6
#define CON_SEL_L_4 GPIO_PIN_1		// PORTA

#define ROW_SEL_L GPIO_PIN_8
#define ROW_SEL_R GPIO_PIN_9

/* USER CODE END PD */

ADC_HandleTypeDef hadc1;

SPI_HandleTypeDef hspi1;

UART_HandleTypeDef huart1;

/* USER CODE BEGIN PV */

// Updated 2D array to store pressure readings
uint16_t pressure_readings[32][64];

// Start and end markers for data transmission
uint8_t start_marker[] = {0xAA, 0xBB};
uint8_t end_marker[] = {0xBB, 0xAA};

// Updated 2D array to store pressure readings
//uint16_t pressure_readings[32][64];
uint16_t dummy_receive[32][64];


// globals
static uint16_t bufA[32][64];
static uint16_t bufB[32][64];
static volatile uint16_t (*tx_buf)[64]   = bufA;  // currently served to SPI
static volatile uint16_t (*fill_buf)[64] = bufB;  // being filled by ADC
static volatile uint8_t frame_ready = 0;


volatile uint8_t data_ready = 0;
volatile uint8_t spi_busy = 0;

volatile uint8_t need_scan  = 0;

/* USER CODE END PV */

void SystemClock_Config(void);
static void MX_GPIO_Init(void);
static void MX_ADC1_Init(void);
static void MX_USART1_UART_Init(void);
static void MX_SPI1_Init(void);
/* USER CODE BEGIN PFP */

void ADC1_Init(void);
void USART1_Init(void);

void DWT_Init(void);
void delay_us(uint32_t us);

uint16_t Read_ADC_Channel0(void);
void USART1_Transmit(const char *data);

void ADG732_Init(void);
void ADG732_SetAddress(uint8_t address);
uint8_t MapColumnIndex(uint8_t col);
void ADG732_SelectChannel(uint8_t col_channel, uint8_t row_channel);
void Collect_Pressure_Readings(void);
void Transmit_Pressure_Readings(void);

/* USER CODE END PFP */

/* USER CODE BEGIN 0 */

// Initialize GPIO pins for ADG732 control
// Initialize the DWT for microsecond delays
void DWT_Init(void) {
    CoreDebug->DEMCR |= CoreDebug_DEMCR_TRCENA_Msk;
    DWT->CYCCNT = 0;
    DWT->CTRL |= DWT_CTRL_CYCCNTENA_Msk;
}

// Microsecond delay using DWT
void delay_us(uint32_t us) {
    uint32_t cycles = (SystemCoreClock / 1000000) * us;
    uint32_t start = DWT->CYCCNT;
    while ((DWT->CYCCNT - start) < cycles);
}

// GPIO Initialization Function
void UD_GPIO_Init(void) {
    __HAL_RCC_GPIOC_CLK_ENABLE();  // Enable GPIOC clock
    //__HAL_RCC_GPIOA_CLK_ENABLE();

    GPIO_InitTypeDef GPIO_InitStruct = {0};
    GPIO_InitStruct.Pin = GPIO_PIN_13;
    GPIO_InitStruct.Mode = GPIO_MODE_OUTPUT_PP;  // Push-Pull Output
    GPIO_InitStruct.Pull = GPIO_NOPULL;  // No Pull-up/down
    GPIO_InitStruct.Speed = GPIO_SPEED_FREQ_LOW;  // Low-speed
    HAL_GPIO_Init(GPIOC, &GPIO_InitStruct);
}


// Initialize ADC1 on Channel 0
/*void ADC1_Init(void) {
    __HAL_RCC_ADC1_CLK_ENABLE();

    ADC_HandleTypeDef hadc1;
    hadc1.Instance = ADC1;
    hadc1.Init.ScanConvMode = ADC_SCAN_DISABLE;
    hadc1.Init.ContinuousConvMode = DISABLE;
    hadc1.Init.DiscontinuousConvMode = DISABLE;
    hadc1.Init.ExternalTrigConv = ADC_SOFTWARE_START;
    hadc1.Init.DataAlign = ADC_DATAALIGN_RIGHT;
    hadc1.Init.NbrOfConversion = 1;
    HAL_ADC_Init(&hadc1);

    ADC_ChannelConfTypeDef sConfig = {0};
    sConfig.Channel = ADC_CHANNEL_0;
    sConfig.Rank = ADC_REGULAR_RANK_1;
    HAL_ADC_ConfigChannel(&hadc1, &sConfig);
}

// Read ADC value from Channel 0
uint16_t Read_ADC_Channel0(void) {
    ADC_HandleTypeDef hadc1;
    hadc1.Instance = ADC1;

    HAL_ADC_Start(&hadc1);
    HAL_ADC_PollForConversion(&hadc1, HAL_MAX_DELAY);
    uint16_t adc_value = HAL_ADC_GetValue(&hadc1);
    HAL_ADC_Stop(&hadc1);

    return adc_value;
}*/

// GLOBAL hadc1 is already declared at file scope

void ADC1_Init(void) {
    __HAL_RCC_ADC1_CLK_ENABLE();

    hadc1.Instance = ADC1;                       // <-- use GLOBAL
    hadc1.Init.ScanConvMode = ADC_SCAN_DISABLE;
    hadc1.Init.ContinuousConvMode = DISABLE;
    hadc1.Init.DiscontinuousConvMode = DISABLE;
    hadc1.Init.ExternalTrigConv = ADC_SOFTWARE_START;
    hadc1.Init.DataAlign = ADC_DATAALIGN_RIGHT;
    hadc1.Init.NbrOfConversion = 1;
    HAL_ADC_Init(&hadc1);

    ADC_ChannelConfTypeDef sConfig = {0};
    sConfig.Channel = ADC_CHANNEL_0;
    sConfig.Rank = ADC_REGULAR_RANK_1;
    sConfig.SamplingTime = ADC_SAMPLETIME_28CYCLES_5; // give the mux time
    HAL_ADC_ConfigChannel(&hadc1, &sConfig);
}

uint16_t Read_ADC_Channel0(void) {
    HAL_ADC_Start(&hadc1);                        // <-- use GLOBAL
    HAL_ADC_PollForConversion(&hadc1, HAL_MAX_DELAY);
    uint16_t v = HAL_ADC_GetValue(&hadc1);
    HAL_ADC_Stop(&hadc1);
    return v;
}


// Initialize USART1 for UART communication
void USART1_Init(void) {
    __HAL_RCC_USART1_CLK_ENABLE();

    huart1.Instance = USART1;
    huart1.Init.BaudRate = 921600;//115200;
    huart1.Init.WordLength = UART_WORDLENGTH_8B;
    huart1.Init.StopBits = UART_STOPBITS_1;
    huart1.Init.Parity = UART_PARITY_NONE;
    huart1.Init.Mode = UART_MODE_TX_RX;
    huart1.Init.HwFlowCtl = UART_HWCONTROL_NONE;
    huart1.Init.OverSampling = UART_OVERSAMPLING_16;
    HAL_UART_Init(&huart1);
}

// Function to transmit data over USART1
void USART1_Transmit(const char *data) {
    HAL_UART_Transmit(&huart1, (uint8_t*)data, strlen(data), HAL_MAX_DELAY);
}

// Initialize GPIO pins for ADG732
void ADG732_Init(void) {
    __HAL_RCC_GPIOB_CLK_ENABLE();

    GPIO_InitTypeDef GPIO_InitStruct = {0};

    // Configure address pins (A0–A4)
    GPIO_InitStruct.Pin = A0_PIN | A1_PIN | A2_PIN | A3_PIN | A4_PIN;
    GPIO_InitStruct.Mode = GPIO_MODE_OUTPUT_PP;
    GPIO_InitStruct.Pull = GPIO_NOPULL;
    GPIO_InitStruct.Speed = GPIO_SPEED_FREQ_HIGH;
    HAL_GPIO_Init(GPIO_PORT, &GPIO_InitStruct);

    // Configure chip select pins
    GPIO_InitStruct.Pin = CON_SEL_R_1 | CON_SEL_R_2 | CON_SEL_R_3 | CON_SEL_L_1 | CON_SEL_L_2 | CON_SEL_L_3 | ROW_SEL_L | ROW_SEL_R;
    HAL_GPIO_Init(GPIO_PORT, &GPIO_InitStruct);

    // Configure chip select pins
	GPIO_InitStruct.Pin = CON_SEL_R_4 | CON_SEL_L_4;
	HAL_GPIO_Init(GPIO_PORT_A, &GPIO_InitStruct);

    // Configure WR and EN pins
    GPIO_InitStruct.Pin = WR_PIN | EN_PIN;
    HAL_GPIO_Init(GPIO_PORT, &GPIO_InitStruct);

    // Set default states
    HAL_GPIO_WritePin(GPIO_PORT, CON_SEL_R_1, GPIO_PIN_SET);
    HAL_GPIO_WritePin(GPIO_PORT, CON_SEL_R_2, GPIO_PIN_SET);
    HAL_GPIO_WritePin(GPIO_PORT, CON_SEL_R_3, GPIO_PIN_SET);
    HAL_GPIO_WritePin(GPIO_PORT_A, CON_SEL_R_4, GPIO_PIN_SET);
    HAL_GPIO_WritePin(GPIO_PORT, CON_SEL_L_1, GPIO_PIN_SET);
	HAL_GPIO_WritePin(GPIO_PORT, CON_SEL_L_2, GPIO_PIN_SET);
	HAL_GPIO_WritePin(GPIO_PORT, CON_SEL_L_3, GPIO_PIN_SET);
	HAL_GPIO_WritePin(GPIO_PORT_A, CON_SEL_L_4, GPIO_PIN_SET);
	HAL_GPIO_WritePin(GPIO_PORT, ROW_SEL_L, GPIO_PIN_SET);
	HAL_GPIO_WritePin(GPIO_PORT, ROW_SEL_R, GPIO_PIN_SET);
    HAL_GPIO_WritePin(GPIO_PORT, WR_PIN, GPIO_PIN_SET);
    HAL_GPIO_WritePin(GPIO_PORT, EN_PIN, GPIO_PIN_RESET);
}

// Set multiplexer address using address pins A0–A4
void ADG732_SetAddress(uint8_t address) {
    HAL_GPIO_WritePin(GPIO_PORT, A0_PIN, (address & 0x01) ? GPIO_PIN_SET : GPIO_PIN_RESET);
    HAL_GPIO_WritePin(GPIO_PORT, A1_PIN, (address & 0x02) ? GPIO_PIN_SET : GPIO_PIN_RESET);
    HAL_GPIO_WritePin(GPIO_PORT, A2_PIN, (address & 0x04) ? GPIO_PIN_SET : GPIO_PIN_RESET);
    HAL_GPIO_WritePin(GPIO_PORT, A3_PIN, (address & 0x08) ? GPIO_PIN_SET : GPIO_PIN_RESET);
    HAL_GPIO_WritePin(GPIO_PORT, A4_PIN, (address & 0x10) ? GPIO_PIN_SET : GPIO_PIN_RESET);
}

// Map logical column index to physical column index
//uint8_t MapColumnIndex(uint8_t col) {
//    if (col < 16) {
//        return col; // 0–15 map directly to 0–15
//    } else if (col < 32) {
//        return 31 - (col - 16); // 16–31 map in reverse to 31–16
//    } else if (col < 48) {
//        return col; // 32–47 map directly to 32–47
//    } else {
//        return 63 - (col - 48); // 48–63 map in reverse to 63–48
//    }
//}

uint8_t MapColumnIndex(uint8_t col) {
    if (col < 16) {
        return 16 + col; // 0–15 map directly to 16–31
    } else if (col < 32) {
        return (31-col); // 16–31 map in reverse to 15–0
    } else if (col < 48) {
        return col; // 32–47 map directly to 32–47
    } else {
        return 63 - (col - 48); // 48–63 map in reverse to 63–48
    }
}

uint8_t MapRowIndex(uint8_t row) {
	if (row <16) {
		return row; // 0–15 map directly to 0–15
	} else {
		return 31 -(row - 16); // 16–31 map in reverse to 31–16
	}
}

// Select a specific row and column
void ADG732_SelectChannel(uint8_t col_channel, uint8_t row_channel_val) {
    // Select row
	uint8_t row_channel;
	if (row_channel_val < 16) {
		//row_channel = 15 - row_channel_val;
		row_channel = row_channel_val;
	}
	else {
		 row_channel = 16 + (31 - row_channel_val);
		//row_channel = row_channel_val;
	}

//	HAL_GPIO_WritePin(GPIO_PORT, ROW_SEL_L, GPIO_PIN_RESET);
//	HAL_GPIO_WritePin(GPIO_PORT, EN_PIN, GPIO_PIN_SET);   // disable (EN is active-low)

	if (row_channel >= 0 && row_channel <8 && col_channel < 32) {
		HAL_GPIO_WritePin(GPIO_PORT, ROW_SEL_L, GPIO_PIN_RESET);
	}
	else if (row_channel >= 0 && row_channel <8 && col_channel >= 32) {
		HAL_GPIO_WritePin(GPIO_PORT, ROW_SEL_R, GPIO_PIN_RESET);
	}
	else if (row_channel >= 8 && row_channel <16 && col_channel < 32) {
		HAL_GPIO_WritePin(GPIO_PORT, ROW_SEL_L, GPIO_PIN_RESET);
	}
	else if (row_channel >= 8 && row_channel <16 && col_channel >= 32) {
		HAL_GPIO_WritePin(GPIO_PORT, ROW_SEL_R, GPIO_PIN_RESET);
	}
//bottom half
	else if (row_channel >= 16 && row_channel <24 && col_channel < 32) {
			HAL_GPIO_WritePin(GPIO_PORT, ROW_SEL_L, GPIO_PIN_RESET);
	}
	else if (row_channel >= 16 && row_channel <24 && col_channel >= 32) {
		HAL_GPIO_WritePin(GPIO_PORT, ROW_SEL_R, GPIO_PIN_RESET);
	}
	else if (row_channel >= 24 && row_channel <32 && col_channel < 32) {
		HAL_GPIO_WritePin(GPIO_PORT, ROW_SEL_L, GPIO_PIN_RESET);
	}
	else {
		HAL_GPIO_WritePin(GPIO_PORT, ROW_SEL_R, GPIO_PIN_RESET);
	}

//	if (col_channel <32) {
//		if (row_channel_val < 16) {
//			//row_channel = 15 - row_channel_val;
//			row_channel_val = 16 + row_channel_val;
//		}
//		else {
//			row_channel_val = 31- row_channel_val;
//			//row_channel = row_channel_val;
//		}
//	}
//
//    ADG732_SetAddress(row_channel_val);
	uint8_t row_address = row_channel_val;
	if (col_channel < 32) {
	    if (row_channel_val < 16) {
	        row_address = 16 + row_channel_val;
	    } else {
	        row_address = 31 - row_channel_val;
	    }
	}
	ADG732_SetAddress(row_address);

    delay_us(1);
    HAL_GPIO_WritePin(GPIO_PORT, WR_PIN, GPIO_PIN_RESET);
    delay_us(1);
    HAL_GPIO_WritePin(GPIO_PORT, WR_PIN, GPIO_PIN_SET);
    HAL_GPIO_WritePin(GPIO_PORT, ROW_SEL_L, GPIO_PIN_SET);
    HAL_GPIO_WritePin(GPIO_PORT, ROW_SEL_R, GPIO_PIN_SET);

//    if (col_channel <32 && row_channel_val < 16) {
//    	row_channel = (31 - row_channel_val);
//    }
	if (col_channel <32) {
		if (row_channel_val < 16) {
			//row_channel = 15 - row_channel_val;
			//row_channel = 31 - row_channel_val;
			//row_channel = 31- row_channel_val;
		}
	}


    //Select Column
//    HAL_GPIO_WritePin(GPIO_PORT, CON_SEL_L_1, GPIO_PIN_RESET);

    ADG732_SetAddress(col_channel);
    delay_us(1);

	if (row_channel >= 0 && row_channel <8 && col_channel < 32) {
		HAL_GPIO_WritePin(GPIO_PORT, CON_SEL_L_1, GPIO_PIN_RESET);
	}
	else if (row_channel >= 0 && row_channel <8 && col_channel >= 32) {
		HAL_GPIO_WritePin(GPIO_PORT, CON_SEL_R_1, GPIO_PIN_RESET);
	}
	else if (row_channel >= 8 && row_channel <16 && col_channel < 32) {
		HAL_GPIO_WritePin(GPIO_PORT, CON_SEL_L_2, GPIO_PIN_RESET);
	}
	else if (row_channel >= 8 && row_channel <16 && col_channel >= 32) {
		HAL_GPIO_WritePin(GPIO_PORT, CON_SEL_R_2, GPIO_PIN_RESET);
	}
//bottom half
	else if (row_channel >= 16 && row_channel <24 && col_channel < 32) {
			HAL_GPIO_WritePin(GPIO_PORT, CON_SEL_L_3, GPIO_PIN_RESET);
	}
	else if (row_channel >= 16 && row_channel <24 && col_channel >= 32) {
		HAL_GPIO_WritePin(GPIO_PORT, CON_SEL_R_3, GPIO_PIN_RESET);
	}
	else if (row_channel >= 24 && row_channel <32 && col_channel < 32) {
		HAL_GPIO_WritePin(GPIO_PORT_A, CON_SEL_L_4, GPIO_PIN_RESET);
	}
	else {
		HAL_GPIO_WritePin(GPIO_PORT_A, CON_SEL_R_4, GPIO_PIN_RESET);
	}

    //HAL_GPIO_WritePin(GPIO_PORT, ROW_CS_PIN, GPIO_PIN_RESET);
//    ADG732_SetAddress(col_channel);
//    delay_us(1);
    HAL_GPIO_WritePin(GPIO_PORT, WR_PIN, GPIO_PIN_RESET);
    delay_us(1);
    HAL_GPIO_WritePin(GPIO_PORT, WR_PIN, GPIO_PIN_SET);

    HAL_GPIO_WritePin(GPIO_PORT, CON_SEL_L_1, GPIO_PIN_SET);
    HAL_GPIO_WritePin(GPIO_PORT, CON_SEL_L_2, GPIO_PIN_SET);
    HAL_GPIO_WritePin(GPIO_PORT, CON_SEL_L_3, GPIO_PIN_SET);
    HAL_GPIO_WritePin(GPIO_PORT_A, CON_SEL_L_4, GPIO_PIN_SET);
    HAL_GPIO_WritePin(GPIO_PORT, CON_SEL_R_1, GPIO_PIN_SET);
    HAL_GPIO_WritePin(GPIO_PORT, CON_SEL_R_2, GPIO_PIN_SET);
    HAL_GPIO_WritePin(GPIO_PORT, CON_SEL_R_3, GPIO_PIN_SET);
    HAL_GPIO_WritePin(GPIO_PORT_A, CON_SEL_R_4, GPIO_PIN_SET);

//	if (row_channel >= 0 && row_channel <8 && col_channel >= 32) {
//		HAL_GPIO_WritePin(GPIO_PORT, CON_SEL_L_1, GPIO_PIN_RESET);
//	}

//    HAL_GPIO_WritePin(GPIO_PORT, EN_PIN, GPIO_PIN_RESET); // enable
//    delay_us(2);
}

// Helper: compute the actual row address for the ADG732 given the logical row and which column half we're on
static inline uint8_t MapRowAddrForSide(uint8_t row_logical, uint8_t col_channel) {
    // Your stated rules:
    // - If col < 32:
    //     - if row < 16: row_addr = 16 + row
    //     - else       : row_addr = 31 - row
    // - If col >= 32:
    //     - if row < 16: row_addr = row (unchanged)
    //     - else       : row_addr = 16 + (31 - row)

    if (col_channel < 32) {
        if (row_logical < 16) {
            return (uint8_t)(16 + row_logical);
        } else {
            return (uint8_t)(31 - row_logical);
        }
    } else {
        if (row_logical < 16) {
            return row_logical;
        } else {
            return (uint8_t)(16 + (31 - row_logical));
        }
    }
}
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
int main(void)
{

  /* MCU Configuration--------------------------------------------------------*/

  /* Reset of all peripherals, Initializes the Flash interface and the Systick. */
  HAL_Init();

  /* Configure the system clock */
  SystemClock_Config();

  /* Initialize all configured peripherals */
  MX_GPIO_Init();
  MX_ADC1_Init();
  MX_USART1_UART_Init();
  MX_SPI1_Init();
  /* USER CODE BEGIN 2 */

  UD_GPIO_Init();
  DWT_Init();
  ADG732_Init();
  ADC1_Init();
  USART1_Init();


  HAL_Delay(1000);
  myPinToggle();




  //Collect_Dummy_Pressure_Readings();
//  Collect_Pressure_Readings();
//  HAL_SPI_TransmitReceive_IT(&hspi1, (uint8_t*)&pressure_readings, (uint8_t *)&dummy_receive, sizeof(pressure_readings));
  // arm first transfer
  //HAL_SPI_TransmitReceive_IT(&hspi1, (uint8_t*)tx_buf, (uint8_t*)dummy_receive, sizeof(bufA));

  //updated on 29 August 2025
  // Start the first scan in the background (optional)
  __DMB();
  frame_ready = 0;  // no new frame yet

  // Arm first SPI transfer with the TX buffer
  HAL_SPI_TransmitReceive_IT(&hspi1,
      (uint8_t*)tx_buf, (uint8_t*)dummy_receive, sizeof(bufA));


  /* USER CODE END 2 */

  /* Infinite loop */
  /* USER CODE BEGIN WHILE */
  while (1)
  {
    /* USER CODE END WHILE */

    /* USER CODE BEGIN 3 */

      // Fill the background buffer while SPI can serve the current one
//      collect_into((uint16_t (*)[64])fill_buf);   // your 32x64 scan
//      __DMB();                                    // memory barrier
//      frame_ready = 1;                            // publish new frame
      // (optional small delay)

	  //Collect_Pressure_Readings();    // Collect readings from the 8x8 matrix
	  //Transmit_Pressure_Readings_RowChunks();


//	  if (need_scan == 1) {					//before 29 august 2025
//		  Collect_Pressure_Readings();
//
//		  need_scan = 0;
//	  }
//
//	  HAL_Delay(1);  // Delay between each full scan to avoid overflow

	collect_into((uint16_t (*)[64])fill_buf);  // scan whole 32x64 into the background buffer
	__DMB();                                   // memory barrier before publishing
	frame_ready = 1;                           // signal “new frame ready for TX”
	// (optional) HAL_Delay(1);

  }
  /* USER CODE END 3 */
}

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
/* USER CODE BEGIN 4 */

//void HAL_SPI_TxRxCpltCallback(SPI_HandleTypeDef *hspi) {
//    if (hspi->Instance == SPI1) {
//        //HAL_UART_Transmit(&huart1, (uint8_t *)"Request Received: ", 18, HAL_MAX_DELAY);
//        //HAL_UART_Transmit(&huart1, rx_buffer, SPI_MSG_LEN, HAL_MAX_DELAY);
//        //HAL_UART_Transmit(&huart1, (uint8_t *)&dummy_receive[1][1], sizeof(dummy_receive[1][1]), HAL_MAX_DELAY);
//        //HAL_UART_Transmit(&huart1, (uint8_t *)"\r\n", 2, HAL_MAX_DELAY);
//
//        //char msg[32];
//        //sprintf(msg, "Value: %u\r\n", dummy_receive[1][1]);
//        //HAL_UART_Transmit(&huart1, (uint8_t*)msg, strlen(msg), HAL_MAX_DELAY);
//
//        // re-arm the transfer
//        //HAL_SPI_TransmitReceive_IT(&hspi1, slave_response, rx_buffer, SPI_MSG_LEN);
//        //HAL_SPI_TransmitReceive_IT(&hspi1, (uint8_t*)pressure_readings, (uint8_t *)dummy_receive, sizeof(pressure_readings));
//        //HAL_SPI_TransmitReceive_IT(&hspi1, (uint8_t*)&pressure_readings[1][1], (uint8_t *)&dummy_receive[1][1], sizeof(pressure_readings[1][1]));
//    	//Collect_Pressure_Readings();
//    	//Collect_Dummy_Pressure_Readings();
//        HAL_SPI_TransmitReceive_IT(&hspi1, (uint8_t*)&pressure_readings, (uint8_t *)&dummy_receive, sizeof(pressure_readings));
//        Collect_Pressure_Readings();
//    }
//}

//// ----- callback (VERY SHORT) -----
//void HAL_SPI_TxRxCpltCallback(SPI_HandleTypeDef *hspi) {
//    if (hspi->Instance == SPI1) {
//        if (frame_ready) {                  // a new frame is ready?
//            // swap buffers
//            uint16_t (*tmp)[64] = (uint16_t (*)[64])tx_buf;
//            tx_buf   = fill_buf;
//            fill_buf = tmp;
//            frame_ready = 0;
//        }
//        // re-arm SPI immediately with the current tx_buf
//        HAL_SPI_TransmitReceive_IT(&hspi1,
//            (uint8_t*)tx_buf, (uint8_t*)dummy_receive, sizeof(bufA));
//    }
//}

//void HAL_SPI_TxRxCpltCallback(SPI_HandleTypeDef *hspi) {
//    if (hspi->Instance == SPI1) {
//        HAL_SPI_TransmitReceive_IT(&hspi1,
//            (uint8_t*)&pressure_readings, (uint8_t*)&dummy_receive,
//            sizeof(pressure_readings));                 // re-arm immediately
//        // now do NOT block here; kick a flag for the main loop to scan
//        need_scan = 1;
//    }
//}

// new ISR function 29 August 2025
void HAL_SPI_TxRxCpltCallback(SPI_HandleTypeDef *hspi) {
    if (hspi->Instance == SPI1) {
        if (frame_ready) {   // publish the freshly scanned frame atomically
            uint16_t (*tmp)[64] = (uint16_t (*)[64])tx_buf;
            tx_buf   = fill_buf;
            fill_buf = tmp;
            frame_ready = 0;
        }
        // re-arm immediately with the current tx_buf
        HAL_SPI_TransmitReceive_IT(&hspi1,
            (uint8_t*)tx_buf, (uint8_t*)dummy_receive, sizeof(bufA));
    }
}



/* USER CODE END 4 */
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


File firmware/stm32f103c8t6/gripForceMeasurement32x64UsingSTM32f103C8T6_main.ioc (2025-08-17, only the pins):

Mcu.UserName=STM32F103C8Tx
PA0-WKUP.Signal=ADCx_IN0
PA10.Signal=USART1_RX
PA13.Signal=SYS_JTMS-SWDIO
PA14.Signal=SYS_JTCK-SWCLK
PA4.Signal=SPI1_NSS
PA5.Signal=SPI1_SCK
PA6.Signal=SPI1_MISO
PA7.Signal=SPI1_MOSI
PA9.Signal=USART1_TX
PC13-TAMPER-RTC.Signal=GPIO_Output
PD0-OSC_IN.Signal=RCC_OSC_IN
PD1-OSC_OUT.Signal=RCC_OSC_OUT

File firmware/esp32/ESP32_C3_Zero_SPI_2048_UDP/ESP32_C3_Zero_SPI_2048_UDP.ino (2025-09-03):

#include <WiFi.h>
#include <WiFiUdp.h>
#include <SPI.h>
#include "ICM20948.h"

// SPI pins
#define PIN_MOSI 4
#define PIN_MISO 3
#define PIN_CLK  2
#define PIN_CS   1

#define PIN_IMU_CS 5

// Wi-Fi Credentials
//const char* ssid = "uofrGuest";
//const char* password = "";
//const char* ssid = "SASKTEL023Y";  //  Melville
//const char* password = "Homescotia5066";
const char* ssid = "CASTLE";  //  Melville
const char* password = "10987654321";

// UDP Settings
// const char* udpAddress = "10.69.167.5"; //Lab IP  // <-- Your PC's local IP address 
//const char* udpAddress = "172.16.1.180"; // Melville House Sou
const char* udpAddress = "192.168.0.133"; // Melville House Shanto
const int udpPort = 12345; // Target UDP port on PC

WiFiUDP udp;

ICM20948 imu;

// SPI & Transfer Config
const int TOTAL_VALUES = 2048;  // 32x64
const int VALUES_PER_CHUNK = 205;  // 205 x 2 = 410 bytes
const int CHUNK_COUNT = 10;

uint16_t readings[TOTAL_VALUES];
uint8_t reading_who_im;

// Compact IMU UDP packet: AA 55 'G' 'Y' + gyroXYZ (6 bytes) + accelXYZ (6 bytes)
// raw units: gyro LSB/°/s (±250 dps => /131.0f), accel LSB/g (±2g => /16384.0f)
void sendIMUPacket() {
  int16_t g[3], a[3];
  imu.readGyroAccel(g, a);

  uint8_t pkt[16];
  uint8_t i = 0;

  auto push16 = [&](int16_t v) {
    pkt[i++] = (uint8_t)((v >> 8) & 0xFF);
    pkt[i++] = (uint8_t)(v & 0xFF);
  };

  pkt[i++] = 0xAA;
  pkt[i++] = 0x55;
  pkt[i++] = 'G';
  pkt[i++] = 'Y';

  // Gyro XYZ (6 bytes)
  push16(g[0]); push16(g[1]); push16(g[2]);
  // Accel XYZ (6 bytes)
  push16(a[0]); push16(a[1]); push16(a[2]);

  udp.beginPacket(udpAddress, udpPort);
  udp.write(pkt, i);
  udp.endPacket();
}




void sendIMUPacketWithMag() {
  int16_t g[3], a[3], m[3];
  imu.readGyroAccelMag(g, a, m);

  // AA 55 'I' 'M' + 9×int16 (big-endian) = 22 bytes total
  uint8_t pkt[22]; uint8_t i = 0;
  auto push16 = [&](int16_t v){ pkt[i++] = (uint8_t)((v>>8)&0xFF); pkt[i++] = (uint8_t)(v&0xFF); };

  pkt[i++] = 0xAA; pkt[i++] = 0x55; pkt[i++] = 'I'; pkt[i++] = 'M';
  push16(g[0]); push16(g[1]); push16(g[2]);
  push16(a[0]); push16(a[1]); push16(a[2]);
  push16(m[0]); push16(m[1]); push16(m[2]);

  udp.beginPacket(udpAddress, udpPort);
  udp.write(pkt, i);
  udp.endPacket();
}




void setup() {
  delay(1000);
  Serial.begin(115200);
  SPI.begin(PIN_CLK, PIN_MISO, PIN_MOSI, PIN_CS);
  pinMode(PIN_CS, OUTPUT);
  digitalWrite(PIN_CS, HIGH);

  pinMode(PIN_IMU_CS, OUTPUT);
  digitalWrite(PIN_IMU_CS, HIGH);

  // Wi-Fi connect
  WiFi.begin(ssid, password);
  Serial.print("Connecting to WiFi...");
  while (WiFi.status() != WL_CONNECTED) {
    delay(500);
    Serial.print(".");
  }
  Serial.println("Connected!");

  udp.begin(WiFi.localIP(), udpPort);
  Serial.println("UDP client ready.");

  imu.begin(PIN_IMU_CS);       // pass your IMU CS pin
  if (!imu.init()) {
    Serial.println("ICM-20948 init failed!");
  } else {
    Serial.println("ICM-20948 ready");
  }

  imu.begin(PIN_IMU_CS);
if (!imu.init()) {
  Serial.println("ICM-20948 init failed!");
}
imu.initMag_AK09916();   // <— add this for magnetometer


}




void loop() {
  // 1. SPI: read 2048 uint16_t = 4096 bytes
  digitalWrite(PIN_CS, LOW);
  delayMicroseconds(10);
  SPI.beginTransaction(SPISettings(1600000, MSBFIRST, SPI_MODE0)); // 400000

  for (int i = 0; i < TOTAL_VALUES; i++) {
    readings[i] = SPI.transfer16(0x0000);  // dummy send to receive
  }

  SPI.endTransaction();
  digitalWrite(PIN_CS, HIGH);

  // 2. Send as 10 UDP chunks of 410 bytes each (205 x uint16_t)
  uint8_t udp_packet[415];  // 2-byte start + 1 index + 410 data + 2-byte end

  for (int chunk = 0; chunk < CHUNK_COUNT; chunk++) {
    int start_index = chunk * VALUES_PER_CHUNK;

    // Header
    udp_packet[0] = 0xAA;
    udp_packet[1] = 0x55;
    udp_packet[2] = chunk;

    // Data
    for (int i = 0; i < VALUES_PER_CHUNK; i++) {
      int data_index = start_index + i;
      uint16_t val = (data_index < TOTAL_VALUES) ? readings[data_index] : 0; // pad with 0 if overflow

      udp_packet[3 + i * 2]     = val & 0xFF;       // LSB
      udp_packet[3 + i * 2 + 1] = (val >> 8) & 0xFF; // MSB
    }

    // Footer
    udp_packet[3 + VALUES_PER_CHUNK * 2] = 0x55;
    udp_packet[4 + VALUES_PER_CHUNK * 2] = 0xAA;

    // Send
    udp.beginPacket(udpAddress, udpPort);
    udp.write(udp_packet, sizeof(udp_packet));
    udp.endPacket();

    delayMicroseconds(100);


  }
  //Serial.println(reading_who_im);

 //Serial.println("Sent full frame as 10 chunks.\n");
  sendIMUPacketWithMag();   // send IMU (gyro+accel+mag) after each pressure frame
  sendIMUPacket();   // send IMU packet after the pressure frame


  delayMicroseconds(100);
  //delay(20);
}

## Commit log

2025-03-17 Project has been created. Currently working on schematic design of the HGF device's PCB
    [GripForceMeasurementDeviceCkt_STM32F103C8T6.kicad_pcb, GripForceMeasurementDeviceCkt_STM32F103C8T6.kicad_sch]
2025-03-20 initial design of schemetic has completed
    [ADG732BSUZ.step, GripForceMeasurementDeviceCkt_STM32F103C8T6.kicad_pcb, GripForceMeasurementDeviceCkt_STM32F103C8T6.kicad_sch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]
2025-05-14 complete schemetic design. working on PCB
    [GripForceMeasurementDeviceCkt_STM32F103C8T6.kicad_pcb, GripForceMeasurementDeviceCkt_STM32F103C8T6.kicad_sch, Waveshare ESP32-C3 Zero.f3d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]
2025-05-19 updated PCB design
    [GripForceMeasurementDeviceCkt_STM32F103C8T6.kicad_pcb, GripForceMeasurementDeviceCkt_STM32F103C8T6.kicad_sch, Waveshare ESP32-C3 Zero.f3d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]
2025-05-20 some photos added
    [GripForceMeasurementDeviceCkt_STM32F103C8T6.kicad_pcb]
2025-05-21 pcb trace complete
    [GripForceMeasurementDeviceCkt_STM32F103C8T6.kicad_pcb, GripForceMeasurementDeviceCkt_STM32F103C8T6.kicad_sch]
2025-05-22 re-configured the pins connection again
    [GripForceMeasurementDeviceCkt_STM32F103C8T6.kicad_pcb, GripForceMeasurementDeviceCkt_STM32F103C8T6.kicad_sch]
2025-05-24 bluetooth module has removed
    [GripForceMeasurementDeviceCkt_STM32F103C8T6.kicad_pcb, GripForceMeasurementDeviceCkt_STM32F103C8T6.kicad_sch]
2025-05-26 GND ground layer filled
    [GripForceMeasurementDeviceCkt_STM32F103C8T6.kicad_pcb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]
2025-06-25 Firmware develepment initiated
    [GripForceMeasurementDeviceCkt_STM32F103C8T6-B_Cu.gbr, GripForceMeasurementDeviceCkt_STM32F103C8T6-B_Mask.gbr, GripForceMeasurementDeviceCkt_STM32F103C8T6-B_Pas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]
2025-08-17 New Design sensor pad visualization through UART completed
2025-08-18 mcu to pc through SPI, UDP pressure data visualization system prototype implemented
2025-09-03 pressueValueWith-gyro-accel-magnato-val with viz added
2026-06-23 new Grip Force 3D Simulator Software implemented with lots of improvements on object tracking precision. Pressure distribution heatmap added. Recorder Added
2026-06-23 docs: Add comprehensive AprilTag processing guide with script variants and frame range examples
    - Document all three AprilTag detector script variants and their use cases
    - Explain key parameters (--start-frame, --end-frame, --process-fps, etc.)
    - Add three practical usage examples: quick test, full video export, and frame range processing
    - Document output files created by each command (annotated video, viewer HTML/JSON)
    - Add processing tips for optimization (speed vs. accuracy trade-offs)
    - Clarify use of detect_apriltag_pose_fixed11_4k_option3_single_state_start_end_frame.py for partial video processing
2026-06-24 Improve viewer synchronization, graph zoom, and persistent standalone layout
    * Fixed timeline sync between 3D viewer, annotated video, pressure distribution, and IMU data
    * Kept viewer_data.json as the main 3D/video timeline
    * Added pressure/IMU start-frame sync without changing native playback speed
    * Added oscilloscope-style time and magnitude zoom controls for pressure and IMU graphs
    * Improved annotated video following behavior
    * Added persistent floating panel layout for position, size, and minimized state
    * Updated standalone viewer launcher to preserve pywebview local storage between app restarts

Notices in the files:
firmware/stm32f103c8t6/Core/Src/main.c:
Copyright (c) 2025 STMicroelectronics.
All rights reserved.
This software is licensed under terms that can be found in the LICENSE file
